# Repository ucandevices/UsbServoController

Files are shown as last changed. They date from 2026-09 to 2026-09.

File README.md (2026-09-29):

# USB-C 12-Channel Servo Controller

Open-source alternative to the [Pololu Mini Maestro 12](https://www.pololu.com/product/1352)
that speaks the **Maestro serial protocols**, so Maestro libraries work unchanged —
plus USB-C, servo-rail current and voltage sensing, on-board scripts. Built for JLCPCB
turnkey assembly, **≈ $4.43 per board at 100 units** against $29.95 for the Maestro.

| | |
|---|---|
| MCU | WCH **CH32V203C8T6**, RISC-V 96 MHz, LQFP-48 |
| Channels | 12 hardware PWM, 50 Hz, 0.5 µs; travel limits per channel (64–4080 µs, 500–2500 default); analog input on 0–7 |
| Host interface | USB-C, CDC serial (no driver); ASCII protocol and the Pololu Maestro Compact / Pololu / Mini SSC protocols |
| Servo power | separate rail on a 5.08 mm screw terminal, 5–13.2 V full function, ~5 A total |
| Sensing | rail current (5 mΩ + INA180A2) and voltage (÷4), overcurrent / LiPo undervoltage cut-off |
| PCB | 66 × 38 mm, 2 layers, all parts top side, 4 × M3 |
| Status | **first board verified on hardware 2026-09-28** — `selftest.py --rail --move` 58/58; channels 1–11 not yet driven with a real servo |

| Document | For |
|---|---|
| [`USER.md`](USER.md) | using the board: wiring, power, tools, command reference, flashing |
| [`tools/README.md`](tools/README.md) | host tools: library, CLI, GUI, scripts, MCP server, release builds |
| this file | design: why each choice, BOM and cost, limitations, what is left before fab |

---

## 1. Quick start

```sh
pip install -r tools/requirements.txt
python tools/servogui.py              # GUI (or --mock with no hardware)
python tools/servoctl.py set 0 1500   # CLI
cd embedded-ch32 && make flash        # build + flash over USB, ~3 s, no jumper
```

**Downloads:** firmware images and the prebuilt GUI for Windows and Linux are on the
[Releases page](https://github.com/ucandevices/UsbServoController/releases/latest).
To build the GUI yourself: `python tools/build_release.py` → `tools/dist/`.

---

## 2. Why the CH32V203C8T6

The hard requirement was a **USB bootloader in ROM**, so a blank chip can be
flashed over USB-C with no programmer. That rules out the STM32F103 the design
started on (USART-only bootloader). Of LQFP-48 parts that have one and are
stocked at JLCPCB:

| Candidate | USB boot on blank chip | Stock | $@100 |
|---|---|---|---|
| **CH32V203C8T6** (chosen) | ✅ | 8,643 | **0.877** |
| CH32X035C8T6 / CH32F203C8T6 | ✅ | ~500 | 0.72 / 1.02 |
| AT32F415CBT7 | ✅ | 10,518 | 1.319 |
| STM32F072C8T6 | ✅ | 2,945 | 2.495 |

Cheapest part with real inventory, a third the price of the STM32F072, and
pin-compatible with the STM32F103 layout (32 of 33 connected pins identical).

Costs of the choice:

- **RISC-V firmware**, WCH HAL, no CubeMX.
- **An ST-Link will not work.** Debug is WCH 2-wire SDI on J9 — needs a
  **WCH-LinkE**. Routine flashing is over USB, so the probe is only for debugging.
- **PB2 is BOOT1** on this chip, so it is tied low by R17 (5.1 kΩ).

---

## 3. Hardware

```
                            U4 INA180A2 (Kelvin across R18) ─► PA5 I_SENSE
J2 Servo V+ ── R18 5mΩ ──┬────────► servo header V+ rail (unfused)
  (VSRV_RAW)              ├─ R19..R22 ÷4 ─► PA4 V_SENSE
                          └─ JP1 ──D2──┐
                                       ├─► HT7533-1 ─► 3V3 ─► CH32V203, LED
USB-C VBUS 5V ─────────────D1──────────┘
GND: one continuous plane, common to both supplies
```

- **Two supply domains, one ground.** D1/D2 are a diode-OR so neither feeds the
  other. Every servo amp crosses R18, so the current reading covers the whole board.
- **JP1** (2-pin header, open by default): fit a shunt cap to run the logic from
  the servo supply with no USB — the Maestro's `VSRV=VIN` block.
- **JP2** (2-pin header): BOOT0 high, for first flash / recovery only.
- **Logic draw ≈ 15 mA**, so the HT7533-1 (100 mA, 2.5 µA quiescent) dissipates
  0.07 W even from 2S LiPo.
- **USB-C**: CC pull-downs R14/R15, SRV05-4 clamps D+, D−, CC1, CC2.
- **Servo signals** are 3.3 V through 220 Ω (R1–R12). Headers are SIG / V+ / GND.

### Channel map

| Ch | 0 | 1 | 2 | 3 | 4 | 5 | 6 | 7 | 8 | 9 | 10 | 11 |
|---|---|---|---|---|---|---|---|---|---|---|---|---|
| Pin | PA0 | PA1 | PA2 | PA3 | PA6 | PA7 | PB0 | PB1 | PA8 | PA9 | PA10 | PB8 |
| Timer | T2C1 | T2C2 | T2C3 | T2C4 | T3C1 | T3C2 | T3C3 | T3C4 | T1C1 | T1C2 | T1C3 | T4C3 |
| Analog | ✅ | ✅ | ✅ | ✅ | ✅ | ✅ | ✅ | ✅ | — | — | — | — |

Reserved: PA4/PA5 rail sensing · PA11/PA12 USB · PA13/PA14 SDI · PD0/PD1 crystal ·
PC13 LED · PB2 BOOT1. LQFP-48 has only 10 ADC pins, and PA4/PA5 went to sensing,
so analog is **8 of 12** — the Maestro 12 has all twelve.

### Rail sensing

| | Current (R18 + U4) | Voltage (R19–R22) |
|---|---|---|
| Parts | 5 mΩ 1 W shunt, INA180A2 gain 50, high side | 4 × 5.1 kΩ, ÷4, 100 nF |
| Full scale | 13.2 A | 13.2 V |
| Resolution | ≈ 3.2 mA | ≈ 3.2 mV |

High side keeps the ground plane unbroken. It measures **total** rail current,
not per channel. The ADC reference is VDDA = the LDO output (no VREF+ on
LQFP-48), so readings are good for thresholds, not calibrated metering. The
firmware trips all channels off after 5 bad readings (~50 ms): 5 A default
overcurrent, and undervoltage chosen automatically (2S → 6.4 V, 3S → 9.6 V,
anything else off). Details in USER.md §4.4.

### Power limits

| Limit | Set by | Value |
|---|---|---|
| Absolute max on J2 | C15/C16, 16 V electrolytics | **16 V** |
| Full function (voltage sense) | ÷4 divider | **13.2 V** |
| Continuous current | 2.4 mm pour between header rows | **~5 A** (6.1 A at 20 °C rise) |

The 24 A terminal is not the limit; the copper behind it is.

### PCB

2 × 1 oz, 1.6 mm, 0.2 mm min trace/space, 0.3/0.6 mm vias. GND is a solid pour
on both layers; SERVO_V+ is carried by three priority-ordered top-layer zones.
Headers along the bottom edge, USB-C right, screw terminal left, MCU centre.

> ⚠️ **F8 (Update PCB from Schematic) deletes H1–H4** — they have no schematic
> symbol. Untick *Delete footprints with no symbols*, or re-add them at
> (16, 4), (61.5, 4), (16, 33), (61.5, 33).

> ⚠️ **HT7533-1 is not pin-compatible with the AMS1117** it replaced (SOT-89:
> GND / VIN+tab / VOUT). The tab is VIN.

---

## 4. Bill of materials and cost

Class: **B** Basic · **P** Preferred (both fee-free) · **E** Extended ($3.07 feeder fee if SMT).

| Ref | Part | LCSC | Class | Qty | $/board |
|---|---|---|---|---|---|
| U1 | CH32V203C8T6, LQFP-48 | C3001172 | E | 1 | 0.8770 |
| U2 | HT7533-1, SOT-89-3 | C14289 | B | 1 | 0.1430 |
| U3 | SRV05-4 ESD, SOT-23-6 | C558418 | E | 1 | 0.0270 |
| U4 | INA180A2, SOT-23-5 | C192764 | E | 1 | 0.1920 |
| J1 | USB-C 16P TYPE-C-31-M-12 | C165948 | E | 1 | 0.1860 |
| J2 | Screw terminal 5.08 mm 2P | C474952 | E (THT) | 1 | 0.1920 |
| J3–J8 | Pin header 1×6 2.54 mm | C37208 | E (THT) | 6 | 0.2520 |
| JP1, JP2 | Pin header 1×2 2.54 mm | C358684 | E (THT) | 2 | 0.0180 |
| Y1 | Crystal 8 MHz SMD5032 | C115962 | B | 1 | 0.2450 |
| D1–D2 | B5819W, SOD-123 | C7420330 | P | 2 | 0.0340 |
| D3 | LED red 0603 | C2286 | B | 1 | 0.0070 |
| R1–R13 | 220 Ω 0603 (servo series + LED) | C22962 | B | 13 | 0.0650 |
| R14–R17, R19–R22 | 5.1 kΩ 0603 | C23186 | B | 8 | 0.0160 |
| R18 | 5 mΩ 1 W shunt, 1206 | C7419996 | E | 1 | 0.0370 |
| C1–C8, C17–C18 | 100 nF 0603 X7R | C14663 | B | 10 | 0.1200 |
| C9–C11 | 10 µF 0603 X5R | C19702 | B | 3 | 0.0960 |
| C12 | 1 µF 0603 | C15849 | B | 1 | 0.0170 |
| C13–C14 | 30 pF 0603 C0G | C1658 | B | 2 | 0.0160 |
| C15–C16 | 470 µF 16 V electrolytic | C46550400 | E | 2 | 0.2140 |
| | | | | **58** | **$2.7540** |

J9 (SDI) is not fitted. Shunt caps (`C100114`, two per board) cannot be fitted
by JLCPCB — order them loose, ≈ $1.80 per 100.

| 100 units | Total | Per board |
|---|---|---|
| Components | $275.40 | $2.754 |
| Assembly: setup $8.18, stencil $1.53, SMT 167 joints $26.72, THT 42 joints $68.88 + $3.58, 6 feeder fees $18.42 | $127.31 | $1.273 |
| PCB fabrication (est.) | ~$40 | ~$0.40 |
| **Total** | **≈ $443** | **≈ $4.43** |

Excludes shipping and duties. Prices are LCSC qty-100; stock checked
2026-09-19/20 (CH32V203 the thinnest at 8,643) — **re-verify before ordering**.

What drives cost:

- **Through-hole soldering is 57 % of assembly.** J3–J8 cost $0.25 in parts and
  $0.59 in hand soldering. SMT-only with loose headers would cut assembly to
  $0.55/board.
- **Unique Extended SMT parts, not unit price.** Hence 220 Ω doubles as the LED
  resistor, 5.1 kΩ serves CC1/CC2/BOOT0/BOOT1/divider, one SRV05-4 replaces
  discrete TVS diodes, and JP1/JP2 share one header part.

---

## 5. Firmware (`embedded-ch32/`)

RISC-V, WCH `ch32v20x` HAL and USB device library, xPack `riscv-none-elf-gcc`
15.2 (`make GCC_PATH=...` to override). Version `USBServoController 0.4`.

| Flash region | Address | Size | Contents |
|---|---|---|---|
| Bootloader | 0x0000 | 12 KB | own USB CDC bootloader (`bootloader/`) |
| Application | 0x3000 | 48 KB | servo firmware |
| Script | 0xF000 | 2 KB | stored board script |
| Settings | 0xF800 | 256 B used | travel limits, Maestro speed/accel (`User/settings.c`, `W`) |

Layout lives in `User/flash_layout.h` and both `Link.ld` files.

```sh
make                 # build/USBServoController-ch32.{elf,hex,bin}
make flash           # BOOT command -> bootloader -> write, CRC-32 check, restart (~3 s)
make hosttest        # on the PC: sense.c protection (21 supply scenarios), maestro.c protocol, ramps and limits (11)
python tools/verify_pinmap_ch32.py   # schematic <-> pin table <-> firmware
```

**Blank chip or recovery:** `make full`, fit JP2, plug in USB,
`wchisp flash build/USBServoController-ch32-full.bin`, remove JP2, **replug**.
Jumping to the ROM bootloader from firmware does not work on this chip (tested),
which is why the board has its own.

**Timing:** 96 MHz timers, PSC 47 → 0.5 µs ticks, ARR 39999 → 20 ms frame.
0.25 µs would need a 4 MHz tick, which only fits 16 bits at ≥ 100 Hz.

**Protocol:** one ASCII command per line, one `OK` / `OK <value>` / `ERR <reason>`
reply. Servo (`S G E X A`), rail sensing (`I U F L P C Z N`), stored script
(`QC QA QS QI QG QR QX`), system (`V BOOT`). Full reference: USER.md §4.3.

**Maestro protocols** (`User/maestro.c`): bytes of `0x80` and above are Pololu
Maestro commands — Compact, Pololu (device 12) and Mini SSC framings, with
on-board speed and acceleration ramps in the Maestro's units. Both protocols
share the port. Reference: USER.md §4.3b.

**Script engine** (`User/script.c`): up to 254 instructions — move with ramp
time, wait, sync, loop, jump, analog wait/branch — compiled from text by
`tools/servoscript.py`, runs without a PC, optionally at power-up.

### Toolchain traps

- **`interrupt("WCH-Interrupt-fast")` is silently dropped by upstream GCC** —
  one warning, then ISRs end in `ret` instead of `mret`. Use
  `interrupt("machine")`.
- **GCC 15 defaults to C23**, where `bool` is a keyword; WCH's `usb_type.h`
  typedefs it. Built with `-std=gnu11` and a patched header.
- **`-march=rv32imac_zicsr_zifencei`** — GCC 15 split CSR and fence.i out.
- **No `printf` at runtime.** A WCH example `printf` in the USB suspend hook hung
  the ISR at bring-up, and PA9 (USART1 TX) is a servo output.

Modified vendor files: `usb_endp.c` (OUT endpoint → parser), `usb_prop.c`
(line coding via `User/cdc_glue.c`), `ch32v20x_it.c` (TIM2 drives servos).

---

## 6. Limitations and Maestro 12 comparison

| Maestro 12 | This board | Fix |
|---|---|---|
| mini-USB | **USB-C** | better |
| no rail sensing | **current + voltage, overcurrent and LiPo cut-off** | better |
| $29.95 | **≈ $4.43** | better |
| 5–16 V servo supply | 5–16 V (13.2 V full function) | parity |
| 12 analog inputs | 8 | respin (pin limit) |
| 5 V signals, 5 V user pin | 3.3 V, no 5 V rail | respin |
| TTL serial, daisy-chain, `ERR` pin, 3 LEDs | USB only, 1 LED | respin |
| Pololu / Compact / Mini SSC protocols | **supported** (0.4): set target(s), speed, acceleration, get position / moving state / errors, go home | parity |
| per-channel min/max 64–4080 µs, 1–333 Hz | **per-channel limits 64–4080 µs**, saved with `W`; fixed 50 Hz | rate: firmware |
| 0.25 µs resolution | 0.5 µs | firmware, at ≥ 100 Hz |
| Speed + acceleration in firmware | **supported** through the Maestro protocol | parity |
| Settings, home positions, startup behaviour in flash | limits and speed/accel stored; no home positions, all channels boot off | firmware |
| Error register, serial-timeout failsafe | protocol-error bit only; no serial timeout | firmware |
| 8 KB script language | 254-instruction motion script | simpler |
| Maestro Control Center | own GUI (`servogui.py`) | Pololu VID-locked |
| 28 × 36 mm | 66 × 38 mm | — |

Other known gaps: **no reverse-polarity protection on J2** — a reversed pack
kills U4 and can vent C15/C16 (a P-FET ideal diode, ≈ $0.19, was deliberately
left out); the current-sense zero (`Z`) is lost at power-off.

### Joining the Maestro ecosystem

Maestro software splits in two. **Runtime control** — nearly every community
library (FRC4564/Maestro, maestro-servo, ROS 1/2 drivers, Node, C++) — opens
the CDC port and speaks the Pololu/Compact/Mini SSC byte protocols **without
checking USB IDs**. **Configuration** (Control Center, `UscCmd`) uses control
transfers bound to Pololu's VID `0x1FFB` and can never work here.

Firmware 0.4 implements those serial protocols, so the runtime libraries work
unchanged: verified on hardware with an unmodified FRC4564 `maestro.py`
(targets, speed, acceleration, position, moving state). One dispatch on the
first byte serves everything: `0xAA` Pololu, `0xFF` Mini SSC, `0x80–0xFE`
Compact, printable ASCII the existing protocol.

Still different from a Maestro: 0.5 µs output steps (0.25 µs needs ≥ 100 Hz
frames), a fixed 50 Hz rate, no home positions, CRC or serial timeout.
Per-channel travel limits (64–4080 µs) and start-up speed/acceleration are
stored on the board with `W` — the GUI's gear button sets the limits. Next steps: configurable frame rate →
serial-timeout failsafe → home positions.

---

## 7. Design notes

**JP1 is a header, not a power-mux IC.** Automatic muxing above 6 V needs an
ideal-diode controller plus FETs (LM5050 +$2.12/board); TPS2116 stops at 5.5 V.
The diode-OR costs $0.03 and JP1 carries only the ~15 mA logic current. A header
and shunt cap ($0.05) beat slide switches on price and have no voltage limit of
their own.

**JP2 is a header too**, so the one jumper every board needs for its first flash
needs no soldering iron.

**HT7533-1 replaced the AMS1117**, which was 66× oversized, drew 5 mA quiescent
and wanted 22 µF tantalum. The HT7533 is cheaper, takes 30 V, and is stable with
the existing 10 µF ceramics.

---

## 8. Repository layout

| Path | Contents |
|---|---|
| `PCB/usbservocontroller/` | KiCad 10 schematic and board; `production/` = Fabrication Toolkit output |
| `embedded-ch32/` | application firmware (`User/`), bootloader (`bootloader/`), host test (`test/`) |
| `embedded-ch32/tools/` | `verify_pinmap_ch32.py`; put a `wchisp` download here (not in the repo) |
| `tools/` | host tools — see [`tools/README.md`](tools/README.md) |
| `USER.md` | user manual |

> The Fabrication Toolkit reads `LCSC` from **footprints**, not symbols. After a
> schematic sync, check `grep -c 'property "LCSC"' usbservocontroller.kicad_pcb`
> (58 today) — a missing field shows as "part not found" at JLCPCB.

---

## 9. Before the next fab run

Checked against the files on 2026-09-29: ERC **0**, DRC **11 errors**, all the
inherent header courtyard overlaps (three rows on a 2.54 mm grid), 0 unconnected.

1. **Fix JP2's board reference.** The footprint is labelled `BOOT0_SEL` instead
   of `JP2`, so DRC reports JP2 missing plus an extra footprint, and fab files
   would carry the wrong designator. Run F8 (with *Delete footprints with no
   symbols* unticked).
2. **Set DNP on J9 and exclude H1–H4 from BOM/position files.** Neither flag is
   set yet, so `EXCLUDE DNP` in `fabrication-toolkit-options.json` does nothing.
3. **R13 220 Ω → 1 kΩ** (C21190, Basic). PC13 is rated 3 mA; 220 Ω drives the
   LED at ~6 mA. Works on the first board, but out of spec.
4. **Remove the 3 duplicated vias** (GND at 11.5, 35.2; I_SENSE and V_SENSE near
   32, 16–18) and decide on the courtyard errors — shrink the courtyards or add
   DRC exclusions so a real error cannot hide among them.
5. **Regenerate `production/`** — it dates from 2026-09-20, before the last
   board edit. Then check that H1–H4 and J9 are gone from `bom.csv` and
   `positions.csv`.
6. **Re-verify JLCPCB stock** (§4).

Re-run the checks with `kicad-cli sch erc usbservocontroller.kicad_sch` and
`kicad-cli pcb drc --schematic-parity usbservocontroller.kicad_pcb`.

---

## License

[MIT](LICENSE) — hardware design files, firmware and host tools.

Files carrying a WCH (Nanjing Qinheng Microelectronics) copyright header — the
`ch32v20x` HAL, USB library, startup code and the WCH-derived files in
`embedded-ch32/User/` — remain under WCH's own terms, which limit their use to
WCH microcontrollers.

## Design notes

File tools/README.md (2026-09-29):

# `tools/` — host-side tooling

Everything here runs on the PC and talks to the board over its USB CDC port. It
is separate from `embedded-ch32/tools/`, which holds `verify_pinmap_ch32.py` —
that one checks the schematic against the firmware and never opens a serial port.

| File | What it is |
|---|---|
| `usc.py` | the driver library — one class, one method per protocol command |
| `servoctl.py` | the CLI, built on `usc.py` |
| `servogui.py` | desktop GUI: sliders, limits, speed, analog inputs, poses & sequences, rail graph, CSV log, flashing |
| `flash.py` | reflash over USB through the board's bootloader, no jumper |
| `servoscript.py` | compile / upload / run scripts the board executes without a PC |
| `servo_mcp.py` | MCP server: AI-agent control with guardrails (needs `mcp>=2`) |
| `build_release.py` | standalone GUI for Windows / Linux (PyInstaller), see section 5 |
| `servoconfig.py` | channel names, limits, poses, sequence — shared by GUI and MCP |
| `examples/` | example board scripts |
| `selftest.py` | first-power-on acceptance test, exit code 0/1 |
| `requirements.txt` | `pyserial`, and nothing else |

```sh
pip install -r requirements.txt

python servoctl.py ports            # find the board
python servoctl.py info             # version, all 12 channels, rail status
python servoctl.py set 0 1500       # move channel 0 to neutral
python servoctl.py sweep 0          # walk it, to check the wiring
python servoctl.py monitor          # watch current and voltage
python servoctl.py stop             # panic stop
python selftest.py --move --rail    # full acceptance run on a new board
```

Every one of those takes `--mock`, which swaps in an in-process emulator of the
firmware's parser and needs no hardware. **The board has never been powered
(README §9), so `--mock` is the only way this tooling has been exercised so
far** — it proves the host code, not the board.

---

## 1. Investigation: what tooling is actually used to drive servos

The question worth answering before writing anything was *what shape* this
tooling should take. The answer comes from the Maestro ecosystem, which README
§6.2 already maps — this section adds what that implies for the host side.

### The ecosystem is Python + pyserial, almost without exception

Every community client for the Mini Maestro is a thin wrapper around pyserial.
[FRC4564/Maestro](https://github.com/FRC4564/Maestro), the most-copied one,
is a single class requiring the pyserial module; it opens a port by name and
writes protocol bytes. [kalhamaar/Maestro](https://github.com/kalhamaar/Maestro)
and [mpiannucci/MiniMaestro](https://github.com/mpiannucci/MiniMaestro) are the
same shape, and [DaveForan/PololuMaestro](https://github.com/DaveForan/PololuMaestro)
is a Python-3/PEP-8 refresh of the same code. Pololu's own documentation ships a
`maestro.py` class that controls a Maestro over its serial interface.

There is no meaningful C++, Rust or Go layer in daily use, and no USB-HID or
libusb layer for *runtime control* at all — the native-USB path exists only for
configuration and script upload, and is what binds to Pololu's vendor ID.

**So: Python, pyserial, one class, no framework.** That is what `usc.py` is.

### The reference GUI, and what it does

Pololu's Maestro Control Center is the thing people actually use day to day, and
it is worth copying the *shape* of. Its tabs, from Pololu's user's guide:

| Tab | What it gives you |
|---|---|
| **Status** | one row per channel: an enable checkbox, a target slider, a position indicator — real-time control and monitoring |
| **Channel Settings** | per-channel mode (servo / input / output), min, max, neutral, speed, acceleration |
| **Sequencer** | a list of *frames*, each a full set of channel positions plus a duration in ms, played back or exported to a script |
| **Script** | write, single-step and run scripts stored on the controller |

The Status tab is the one that matters first, and it is the one a CLI can only
approximate — `servoctl.py monitor` is the closest thing here. It is free, and
runs on Windows and Linux.

**It can never work against this board.** Control Center, `UscCmd` and the
Pololu USB SDK all bind to USB vendor ID `0x1FFB`, which is Pololu's USB-IF
assignment. That is not clonable, so an equivalent host tool is part of this
project rather than optional polish — which is the reason `tools/` exists as a
first-class directory and not a scratch folder.

### Port discovery is a solved convention

pyserial's `serial.tools.list_ports.comports()` returns objects carrying `vid`,
`pid`, `serial_number` and a description, and matching on VID/PID is the
standard way host tools find their board. The wrinkle here is that the firmware
ships **WCH's stock CDC identifiers, `0x1A86:0xFE0C`** (`USBLIB/CONFIG/usb_desc.c`),
not its own — so VID/PID alone would also match any other WCH CDC device on the
machine. `usc.py` therefore filters on VID/PID *and then* probes each candidate
with `V`, keeping the one that answers with the version string. Projects that hit
the same problem solve it the same way: CircuitPython's tooling matches on the
CDC interface *name* rather than on IDs for exactly this reason.

> Worth considering for a later firmware revision: WCH does not police its VID,
> but shipping a distinct PID and a product string of your own would make
> discovery exact instead of probabilistic.

### What this means for the ordering of work

1. **A Python library + CLI first.** It matches what the ecosystem already does,
   it is what a person needs on the bench the hour the first board arrives, and
   everything else is built on top of it. ← *this directory*
2. **A Pololu/Compact protocol layer in the firmware second** (README §6.2),
   because it makes all fourteen libraries in that table work unmodified. At
   that point `usc.py` becomes a *second* way in, not the only way.
3. **A Control Center equivalent last**, once the firmware has settings worth
   persisting. A sequencer — frames of positions plus durations — is the single
   most-copied feature and is pure host-side code; it needs nothing from the
   firmware that `S` does not already provide.

---

## 2. `usc.py` — the library

```python
from usc import ServoController

with ServoController.open() as dev:        # or .open("COM5"), or .mock()
    print(dev.version())
    dev.set_us(0, 1500)                    # S 0 1500 -- also enables ch0
    print(dev.get_us(0))                   # G 0
    print(dev.status())                    # F -> Status(faults, mA, mV, rail)
    dev.stop_all()                         # X
```

One method per command in README §5: `version`, `set_us`, `get_us`, `enable`,
`disable`, `stop_all`, `read_analog`, `current_ma`, `voltage_mv`, `read_raw`,
`tare`, `status`, `clear_faults`, `set_limits`, `reboot_to_bootloader`. Anything
not covered goes through `dev.command("...")`, which returns the raw reply line
and raises `DeviceError` on `ERR`.

Two firmware behaviours the library documents rather than hides, because both
surprise people:

- **`S` enables the channel.** `Servo_SetPulseUs()` sets `s_enabled`
  unconditionally, so setting a pulse width is what starts a servo moving. There
  is no "set the target but stay off".
- **`G` returns `0` for a disabled channel**, not its last pulse width. So
  `set_us(0, 1500); disable(0); get_us(0)` gives `0`, and the stored width is
  not readable back. `positions()` returns the same 0-means-off convention.

### The emulator

`MockDevice` reimplements `protocol.c`'s dispatch and a simplified `sense.c` in
about 150 lines. It exists because the board has never been run, and it is
deliberately *not* a simulator: no timers, no ADC noise, no USB. It catches
host-side mistakes — a malformed command, a misparsed reply, a wrong error
string — and nothing else. Simulated current is `12 mA + 120 mA per enabled
channel`, enough for the fault logic to be exercised.

---

## 3. `selftest.py` — the bring-up test

Ordered so that a wiring fault cannot become a damaged servo: everything
read-only happens before anything moves, and `--move` is opt-in.

```
1. Identity          V answers, and says 12ch
2. Boot state        all 12 channels report disabled  <- an unconfigured board must not move
3. Error handling    seven rejections, each with the right ERR reason
4. Rail sensing      F/I/U/N; I_SENSE and V_SENSE not pinned at 0 or 4095
5. Analog inputs     0-7 return counts, 8-11 return ERR noanalog
6. Movement          --move only, one channel at a time, each parked before the next
7. Current sense     moves ch0, checks the peak current rises (servo on ch0)
8. Panic stop        X really does disable everything
```

It always ends with `X`, including on failure or Ctrl-C, so a failed run leaves
nothing energised. Exit code 0/1 makes it usable as a production go/no-go test.

Checks 4 and 7 are the ones that matter most on a first article, because they
are what distinguishes "R18/U4/PA5 are correctly assembled" from "the firmware
compiles". A current reading that does not change when a channel is enabled means
the sense path is not connected, whatever the numbers look like.

---

## 4. Two findings from reading the firmware alongside this

**A latched fault does not block `S`.** README §5 states that while a fault is
latched, `E <ch> 1` is refused with `ERR fault` — and it is, in `protocol.c`'s
`case 'E'`. But `case 'S'` has no such check, and `Servo_SetPulseUs()` sets
`s_enabled = true`. So `S 0 1500` re-energises a channel straight through the
interlock, and `sense.c` will only trip again after `SENSE_TRIP_COUNT` further
task periods. The fix is one line — the same `Sense_Faults() != 0` guard in
`case 'S'` — but it is a firmware change, so it is noted here rather than made.
Until then, host code must treat the interlock as advisory: `selftest.py` checks
`status()` after each movement instead of relying on it.

**`BOOT` reboots into the board's own USB bootloader** (verified on hardware
2026-09-28). It is what `flash.py` uses to reflash without a jumper: `python
flash.py [app.bin] [--port COMx]` — BOOT, erase, write (page 0 last), CRC-32
verify, start; about 3 s. `servoctl.py boot --yes` does only the first step and
leaves the board waiting in the bootloader (LED at 5 Hz). The bootloader
protocol is documented in `embedded-ch32/bootloader/bl_main.c`.

---

## 5. Standalone GUI release (`build_release.py`)

`servogui.py` packaged with PyInstaller into one executable, zipped with
`examples/` and the application firmware image (so the Firmware tab works):

    python build_release.py                       # Windows -> dist/ServoGUI-windows-x64.zip
    wsl -d Ubuntu -- ~/servogui-venv/bin/python build_release.py   # Linux -> dist/ServoGUI-linux-x64.tar.gz

It builds for the OS it runs on, so the Linux build runs in WSL (venv at
`~/servogui-venv` with `pyinstaller pyserial`; needs `python3-tk`). A frozen
build keeps `servogui.json` next to the executable and flashes by re-running
itself as `ServoGUI --run-flash <image>`. On Linux the user must be in the
`dialout` group to open the serial port.

## Sources

- [FRC4564/Maestro](https://github.com/FRC4564/Maestro) — the most-copied Python client
- [kalhamaar/Maestro](https://github.com/kalhamaar/Maestro), [mpiannucci/MiniMaestro](https://github.com/mpiannucci/MiniMaestro), [DaveForan/PololuMaestro](https://github.com/DaveForan/PololuMaestro)
- [Pololu Maestro Servo Controller User's Guide](https://www.pololu.com/docs/0j40/all) — and its [Status](https://www.pololu.com/docs/0J40/4.a), [Channel Settings](https://www.pololu.com/docs/0J40/4.b) and [Sequencer](https://www.pololu.com/docs/0J40/4.c) tabs
- [Pololu related resources](https://www.pololu.com/docs/0J40/10) — the official `maestro.py`
- [pySerial `serial.tools.list_ports`](https://pyserial.readthedocs.io/en/stable/tools.html)

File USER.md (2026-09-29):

# USB-C 12-Channel Servo Controller — User Manual

This is the manual for **using** the board: what is on it, how to wire it, how to
drive it from a PC, and how to build and flash the firmware. The design
rationale, costs and known limitations live in [`README.md`](README.md); this
file only repeats what you need at the bench.

> ⚠️ **Prototype status.** Board revision v1 has **not yet been run on real
> hardware.** Everything here is taken from the schematic, the board file and the
> firmware source, and the host tools have only been exercised against their
> built-in emulator (`--mock`). Treat the first boards as bring-up units and run
> the self-test (§3.4) before trusting one with servos you care about.

**Contents**

1. [Hardware manual](#1-hardware-manual) — board tour, connectors, power, wiring
2. [First power-on](#2-first-power-on) — the safe sequence for a new board
3. [Tooling manual](#3-tooling-manual) — `servoctl`, `selftest`, the Python library
4. [Embedded manual](#4-embedded-manual) — protocol, behaviour, build, flash
5. [Troubleshooting](#5-troubleshooting)
6. [Quick reference card](#6-quick-reference-card)

---

## 1. Hardware manual

### 1.1 What it is

A 12-channel hobby-servo controller driven over USB-C. The PC sends text
commands to a virtual serial port; the board turns them into standard RC servo
pulses. It also measures the **current and voltage of the servo supply** and
can shut every servo off on overcurrent or a flat battery.

| | |
|---|---|
| MCU | WCH CH32V203C8T6 (32-bit RISC-V, 96 MHz) |
| Host interface | USB-C, appears as a serial (CDC) port — no driver on Windows 10+, Linux, macOS |
| Servo outputs | 12 channels, 3.3 V logic pulses, 50 Hz, 0.5 µs resolution; 500–2500 µs by default, settable per channel from 64 to 4080 µs |
| Analog inputs | channels 0–7 only, **0–3.3 V** |
| Servo supply | separate, via screw terminal J2 — see §1.4 for limits |
| Rail monitoring | servo-rail current (0–13.2 A range) and voltage (0–13.2 V range) |
| Indicator | one red LED (heartbeat) |
| Size | 66 × 38 mm, 4 × M3 mounting holes |

### 1.2 Board tour

Hold the board **component side up, USB-C connector on the right.**

```
                                  TOP EDGE
 ┌─────────────────────────────────────────────────────────────────────┐
 │ (H1)          J9  SDI debug (not fitted)      JP2                (H2) │
 │               3V3 DIO CLK RST GND             BOOT0      USB SERVO   │
 │                ○   ○   ○   ○   ○               ▯          CONTROLLER │
 │  C15                                           ▯          v1         │
 │ (470µF)                 Y1        ┌──────┐                        ┌──┤
 │                                   │  U1  │                   J1   │  │ USB-C
 │  J2 SERVO PWR  ─                  │CH32V │                        │  │
 │   [−]  GND                        └──────┘                        └──┤
 │   [+]  V+   +                                                        │
 │                        0  1  2  3  4  5  6  7  8  9  10 11           │
 │  JP1 ▯▯   VSRV    SIG  ○  ○  ○  ○  ○  ○  ○  ○  ○  ○  ○  ○   SIG      │
 │           LOGIC   V+   ○  ○  ○  ○  ○  ○  ○  ○  ○  ○  ○  ○   V+   D3  │
 │ (H3)              GND  ○  ○  ○  ○  ○  ○  ○  ○  ○  ○  ○  ○   GND  LED │
 └─────────────────────────────────────────────────────────────────(H4)┘
                                 BOTTOM EDGE
```

| Ref | What | Where |
|---|---|---|
| **J1** | USB-C — data and logic power | right edge |
| **J2** | Servo power in, 5.08 mm screw terminal | left edge. **Lower screw = `+`**, upper screw = `−` (GND). Silkscreen `+` / `−` marks each side. |
| **J3–J8** | 12 servo ports, 3 rows × 12 | along the bottom. Channel numbers printed above; row names `SIG` / `V+` / `GND` printed at the right end |
| **JP1** | "VSRV / LOGIC" jumper — power the logic from the servo supply | left edge, below J2 |
| **JP2** | BOOT0 jumper — enter the USB bootloader | top edge, centre |
| **J9** | WCH SDI debug header, **not fitted** | top edge, left of centre |
| **D3** | red status LED | bottom right |
| **H1–H4** | M3 mounting holes, 3.2 mm | corners; centres 45.5 × 29 mm apart |

### 1.3 Servo ports (J3–J8)

Each **column** is one channel. Each column has three pins, from top to bottom:

| Row | Pin | Standard servo wire colour |
|---|---|---|
| top (toward the chip) | **SIG** — the pulse | orange / yellow / white |
| middle | **V+** — servo power, straight from J2 | red |
| bottom (toward the board edge) | **GND** | brown / black |

This is the standard Futaba/JR/Hitec order, so a normal 3-wire servo plug goes on
**with the dark wire toward the bottom edge.** Channel 0 is on the left,
channel 11 on the right.

| Ch | MCU pin | Timer | Analog in? |
|---|---|---|---|
| 0 | PA0 | TIM2_CH1 | ✅ |
| 1 | PA1 | TIM2_CH2 | ✅ |
| 2 | PA2 | TIM2_CH3 | ✅ |
| 3 | PA3 | TIM2_CH4 | ✅ |
| 4 | PA6 | TIM3_CH1 | ✅ |
| 5 | PA7 | TIM3_CH2 | ✅ |
| 6 | PB0 | TIM3_CH3 | ✅ |
| 7 | PB1 | TIM3_CH4 | ✅ |
| 8 | PA8 | TIM1_CH1 | — |
| 9 | PA9 | TIM1_CH2 | — |
| 10 | PA10 | TIM1_CH3 | — |
| 11 | PB8 | TIM4_CH3 | — |

Every SIG pin has a **220 Ω series resistor** between the MCU and the header.

**What can be connected to a servo port:**

| Device | Works? | Notes |
|---|---|---|
| Standard analog / digital hobby servo | ✅ | the intended use |
| Continuous-rotation servo | ✅ | 1500 µs ≈ stop; trim per servo |
| ESC (brushed or brushless) | ✅ | 1000–2000 µs is inside the range. **See the BEC warning below.** |
| Servos that need 5 V logic pulses | ⚠️ | most accept 3.3 V; a few older ones do not |
| Potentiometer / 0–3.3 V sensor on ch 0–7 | ⚠️ | read with the `A` command — see limits in §1.7 |
| 5 V sensor output | ❌ | inputs are 0–3.3 V only; 5 V will inject current into the MCU |
| LEDs, relays, logic outputs | ❌ | firmware has no digital-output mode yet |
| UART / TTL serial device | ❌ | firmware does not support it yet |

> ⚠️ **ESC BEC warning.** Many ESCs *output* 5–6 V on their red wire (a "BEC").
> Plugged into this board, that output lands on the shared **V+ rail** together
> with whatever is on J2. Two supplies fighting on one rail can damage both.
> If you plug in an ESC with a BEC while J2 also has a supply, **pull the red
> wire out of the ESC's plug** (or use only the ESC's BEC to power the rail and
> leave J2 empty).

### 1.4 Power

The board has **two independent power domains** that share a common ground:

- **Logic** (MCU, USB, LED) — 3.3 V from an on-board regulator, fed from USB-C
  or, if JP1 is fitted, from the servo supply.
- **Servo rail** (V+ row on all 12 ports) — whatever you connect to J2, passed
  straight through. **The board does not regulate servo power.**

```
  USB-C VBUS 5V ──D1──┐
                      ├──► HT7533 3.3V LDO ──► MCU, LED
  J2 + ──[5mΩ shunt]──┼──► V+ on all 12 servo ports
                      │
                      └── JP1 ──D2──┘   (JP1 fitted = logic can run from J2)
  J2 − ─────────────────── GND (common to everything)
```

**Servo supply limits**

| | Value |
|---|---|
| Supply voltage | **choose it to match your servos** — see below |
| Absolute maximum on J2 | **16 V** (set by the 16 V bulk capacitors) |
| Maximum for correct voltage reading | 13.2 V |
| Continuous current, whole board | **≈ 5 A total** across all channels |
| Terminal wire size | 12–22 AWG; use **18 AWG or thicker** for loads over 2 A |

> The screw terminal itself is rated 24 A, but the copper behind it is not.
> Budget about **5 A total** — a dozen small servos holding position, or three
> or four working hard.

**Choosing the servo supply.** Since the voltage on J2 goes straight to every
servo, pick it for your servos, not for the board:

| Supply | Suits |
|---|---|
| 4.8 V (4× NiMH) | standard servos |
| 5–6 V BEC / bench supply | standard servos — the most common choice |
| 7.4 V (2S LiPo), 8.4 V charged | **HV (high-voltage) servos only** |
| 11.1 V (3S LiPo) | almost no servos — only if yours are rated for it |

> ⛔ **No reverse-polarity protection.** Connecting the servo supply backwards
> will destroy the current-sense chip (U4) and can make the two large capacitors
> vent. Check `+` and `−` **before** tightening the screws, every time. Wire the
> supply with the power switched off.

> **Battery protection is automatic for LiPo packs.** About 100 ms after a servo
> supply appears, the firmware recognises a **2S or 3S LiPo** by its voltage and
> sets a 3.2 V/cell cutoff. Any other supply (5 V / 6 V BEC, NiMH, bench supply)
> gets **no** undervoltage cutoff unless you set one. Details and overrides are in
> §4.4.

### 1.5 The two jumpers

Both are 2-pin headers closed with a standard 2.54 mm shunt cap. The board ships
**with both open**; the caps come loose in the bag.

**JP1 — "VSRV / LOGIC": run the logic from the servo supply**

| JP1 | Logic powered from | Use when |
|---|---|---|
| **open** (default) | USB only | normal use with a PC. Recommended. |
| **fitted** | USB **or** servo supply, whichever is higher | the USB port's power is weak (long cable, unpowered hub), or you want the board to stay alive with USB unplugged |

Diodes on both paths stop either supply back-feeding the other, so it is safe
to have USB and J2 connected with JP1 fitted.

> **Standalone operation:** with JP1 fitted and the servo supply on, the board
> runs a stored script with no PC at all — upload it with autorun (§3.1c) and it
> starts at every power-up. Without a stored autorun script, every channel stays
> off after power-up until a host sends commands.

**JP2 — BOOT0: firmware update mode**

| JP2 | At power-up the board runs |
|---|---|
| **open** (normal) | the servo-controller firmware |
| **fitted** | WCH's ROM bootloader — first flash of a blank chip, or recovery (§4.7) |

Routine firmware updates **do not use JP2**: `flash.py` reboots the board into
its own USB bootloader over the serial port (§4.7). JP2 is for a blank chip, or
for recovering a board whose application no longer answers on USB. It is only
read **at power-up** — fit it, *then* plug in USB, and remove it afterwards.

### 1.6 USB-C

- Any USB-C cable to a USB-A or USB-C port works. The board is a USB 2.0
  full-speed device and draws about 15 mA (estimated, not yet measured).
- Either plug orientation works.
- Data lines and the CC pins are ESD-protected.
- USB **never** powers the servos. With only USB connected, the board runs and
  answers commands, but nothing on the V+ row has power.

### 1.7 Electrical limits of the signal pins

| | |
|---|---|
| Output high / low | 3.3 V / 0 V through 220 Ω |
| Analog input range (ch 0–7) | **0 to 3.3 V** — never exceed |
| Analog reading | 12-bit, 0–4095 counts over 0–3.3 V |
| 5 V tolerance | **not guaranteed** — do not feed 5 V into a SIG pin |

> ⚠️ **Analog inputs are shared with outputs.** A channel that is not driving a
> servo is held **low** by the MCU, and is switched to input only for the ~20 µs
> of each reading. So a potentiometer (1–10 kΩ) wired as a divider between 3.3 V
> and GND reads correctly, but a sensor with a strong output will be fighting the
> pin between readings. Keep analog sources high-impedance, and **never** read a
> channel that has a servo plugged in and enabled — the reading briefly
> interrupts its pulse.

> ⛔ **Where to get 3.3 V for a potentiometer.** The servo header has **no
> 3.3 V pin** — its middle row is the servo supply (5–13 V). A pot wired between
> the header's V+ and GND puts up to the full servo voltage on the ADC pin.
> Take 3.3 V and GND from **J9 pin 1 (3V3) and pin 5 (GND)** instead — solder a
> 1×5 2.54 mm header there (§1.8). Wire: pot ends → J9.1 and J9.5, wiper → the
> channel's **SIG** pin (top row).

> ⚠️ **A servo plug reversed by one row** puts V+ on the SIG pin. The 220 Ω
> resistor limits the damage, but at 6–8 V it still pushes 10–20 mA into the MCU
> pin. Check plug orientation before powering J2.

### 1.8 J9 — debug header (developers only)

Not fitted. Solder a 1×5 2.54 mm header if you need live debugging.

| Pin | Signal |
|---|---|
| 1 | 3V3 |
| 2 | SDI_DIO (PA13) |
| 3 | SDI_CLK (PA14) |
| 4 | NRST |
| 5 | GND |

> ⛔ This is **WCH's 2-wire SDI protocol, not ARM SWD.** An ST-Link, J-Link or
> other ARM probe **will not work.** Use a **WCH-LinkE**. You do not need J9 at
> all to update the firmware — that goes over USB (§4.7).

### 1.9 Status LED (D3)

| LED | Meaning |
|---|---|
| one short blip per second | running, idle, servo supply present on J2 |
| **two** short blips per second | running, idle, **no servo supply** on J2 |
| **steady on** | a **stored script is running** (§3.1c) |
| fast even flashing, 10 Hz | **fault latched** (overcurrent or undervoltage): every channel was dropped. Clear it with `C`, `servoctl.py clear` or the GUI's **Clear faults** |
| even flashing, 5 Hz | in the USB **bootloader** (after `BOOT`, or an interrupted flash) — run `tools/flash.py` |
| off | no power, or the ROM bootloader (JP2 fitted) |
| stuck on with no script running, or stuck off while powered | firmware has hung — unplug and re-plug |

Only one pattern shows at a time; a fault outranks a running script, which
outranks the idle patterns.

---

## 2. First power-on

Follow this order on a new board. It is arranged so that a wiring or assembly
fault shows up **before** anything moves.

1. **Inspect.** Look for solder bridges on U1 (the square 48-pin chip) and on the
   USB-C connector. Check that JP1 and JP2 are **open**.
2. **USB only.** Plug in USB-C, no servo supply, no servos. The LED should start
   blinking within a second.
3. **Find the port.**
   ```sh
   cd tools
   pip install -r requirements.txt
   python servoctl.py ports
   ```
4. **Safe self-test** — nothing moves:
   ```sh
   python selftest.py
   ```
   It must end with `RESULT: PASS`. The rail-voltage check is skipped because
   there is no servo supply yet.
5. **Connect the servo supply** — **power off**, polarity checked twice — to J2,
   with **no servos plugged in**. Switch it on.
6. **Check the protection limits** the board picked for your supply (§4.4):
   ```sh
   python servoctl.py limits
   ```
   A LiPo should show a 6400 mV (2S) or 9600 mV (3S) undervoltage limit marked
   `(auto)`; any other supply shows `undervoltage off`. Set your own with
   `limits <mA> <mV>` if you want one.
7. **Zero the current sensor** with nothing drawing current:
   ```sh
   python servoctl.py tare
   ```
8. **Check the rail:**
   ```sh
   python servoctl.py sense
   ```
   Voltage should match your supply, current should be near 0, no faults.
9. **One servo on channel 0**, then:
   ```sh
   python servoctl.py sweep 0 --park
   ```
10. **Full acceptance test**, with one servo on each channel you plan to use:
    ```sh
    python selftest.py --move --rail
    ```

---

## 3. Tooling manual

All host tools live in `tools/`, are plain Python 3, and depend only on
`pyserial`.

```sh
cd tools
pip install -r requirements.txt
```

### 3.1 Finding the board

The board shows up as a serial port:

| OS | Port name |
|---|---|
| Windows 10/11 | `COMn` (Device Manager → Ports) — built-in driver, nothing to install |
| Linux | `/dev/ttyACM0`, `/dev/ttyACM1`, … |
| macOS | `/dev/cu.usbmodem…` |

`servoctl.py ports` lists every serial port and marks the candidates. The tools
auto-detect the board by its USB ID (`1A86:FE0C`) **and** a version handshake,
because that ID is WCH's generic one and other WCH gadgets share it. To skip
auto-detection, pass `--port`:

```sh
python servoctl.py --port COM5 info
python servoctl.py --port /dev/ttyACM0 info
```

On Linux, add yourself to the `dialout` group once (`sudo usermod -aG dialout
$USER`, then log out and in) so you do not need `sudo`.

### 3.1b `servogui.py` — desktop GUI

```sh
python tools/servogui.py              # auto-detect;  --port COM52  /  --mock
```

**Channels (left).** Tick **on** to drive a channel, drag the slider to move it.
**Enable all** turns on every servo channel at its slider position. **STOP**,
the **space bar** or **Esc** is the panic stop (`X`). The **⚙** button per row sets:

| Setting | What it does |
|---|---|
| Name | shown in the row, poses and CSV headers |
| Min / Max | travel limits in µs — the slider cannot go past them. Set them just inside the servo's mechanical end stops: a servo pushing against a stop stalls and draws its full stall current (~2.3 A for an MG995) |
| Speed | µs per second, 0 = instant. Ramping is done by the GUI in 50 ms steps, so moves are smooth and current spikes smaller |
| Mode | **servo**, or **input** (channels 0–7): the row becomes a live analog bar, 0–4095 counts / 0–3.3 V, and the channel is never driven |

**Rail tab.** Live current and voltage, a 10 s current graph with peak hold,
**Clear faults**, **Tare**, the **Protection** limits (`P`; offered up to
7500 mA — the board's continuous budget is ~5 A (§1.4), its narrowest rail trace
7.8 A; they reset to 5000 mA at power-up), and **Record CSV**, which logs
current, voltage, faults, every channel's pulse width and the analog inputs every
50 ms.

**Poses & sequence tab.** **Save current** stores every channel that is on as a
named pose; **Go to** (or double-click) moves back to it. A sequence is a list of
poses, each with a **move** time (how long to get there; 0 = each channel's own
speed) and a **hold** time. **Play** runs it **repeat** times (0 = forever; the same count goes into a board script uploaded with **Upload sequence**); STOP
or a fault ends it. This is the replacement for the Maestro's sequencer.

**Script tab.** A text editor for board scripts (§3.1c) with syntax colouring:
**Check (F5)** compiles and shows the instruction listing, or marks the bad line
in red; **Upload** / **Upload + Run** store it on the board (with **autorun at
power-up** if ticked); **Run** / **Stop** control the stored script; **Read from
board** turns the stored script back into editable text; **From sequence**
starts from the Poses tab's sequence; **Help** lists every statement.
New / Open / Save / Save as work on `.txt` files (Ctrl+S saves). The editor
text is kept between runs even if unsaved. Space typed in the editor does not
stop the servos; **Esc** always does.

**Firmware tab.** **Flash firmware** runs `flash.py` on the chosen application
image and shows its output — no jumper — then reconnects (§4.7). Build the image
first with `make`.

Settings, poses and the sequence are saved in `tools/servogui.json`. A latched
fault drops every channel; the GUI shows it and **Clear faults** re-arms. Uses
only tkinter (bundled with Python) and pyserial.

### 3.1c `servoscript.py` — scripts that run on the board, without a PC

The firmware has a small script engine. A script is compiled on the PC, stored
in the last 4 KB of flash, and run by the board itself — it keeps going with
the USB cable unplugged, and with **autorun** it starts at every power-up.
Up to 254 instructions; timing comes from the servo timer, to 1 ms.

```sh
python tools/servoscript.py check  tools/examples/wave.txt        # compile, list
python tools/servoscript.py upload tools/examples/wave.txt --run  # store + start
python tools/servoscript.py upload wave.txt --autorun             # start at power-up
python tools/servoscript.py status | run | stop | dump
python tools/servoscript.py from-gui -o seq.txt                   # GUI sequence -> script
```

| Statement | Meaning |
|---|---|
| `name:` | a label, target of `loop` / `jump` |
| `move <ch> <us> [<time>]` | ramp to `<us>` over `<time>` (default 0 = jump). Does **not** wait: moves on *different* channels run together. A second move of the *same* channel first waits for the one before (the compiler adds a `sync` and says so). A channel that is off ramps from where it was last driven (1500 µs if never), over the full time |
| `pose <name> [<time>]` | move every channel of a GUI pose |
| `sync` | wait until every move has **arrived** (`wait` just pauses; `sync` waits for the servos) |
| `wait <time>` / `sleep <time>` | pause for a fixed time. **A plain number is milliseconds** (`2` = 2 ms): write `2s`, `1.5s` or `2000` |
| `off <ch>` / `off all` | stop driving (the servo goes limp). A channel still moving finishes its move first |
| `loop <label> [<n>]` | go back to `<label>`; the block runs `n` times in total, forever without `n` |
| `jump <label>` | go to `<label>` |
| `waitin <ch> > <v>` / `< <v>` | wait for analog input `ch` (0–7) to go above / below `v` (0–4095) |
| `ifin <ch> > <v>` / `< <v>` | run the next statement only if the condition holds |
| `end` | stop; moves still running finish first, then servos hold (same at the end of the script) |

Channels are numbers or the names set in the GUI, and positions are clamped to
each channel's GUI limits, with a warning. A latched rail fault or `X` stops a
running script. The LED blinks four times faster while a script runs. The GUI's
**Poses & sequence** tab can upload its sequence (or a script file) to the board
and run or stop it; the MCP server can too. Pose names used in scripts cannot
contain spaces (the GUI now saves them with underscores).

**Standalone:** fit **JP1** so the logic runs from the servo supply, upload with
`--autorun`, unplug USB — the script starts whenever the servo supply comes on.

### 3.1d `servo_mcp.py` — AI agent control (MCP)

An MCP server that lets an AI agent drive the board through typed tools
instead of shell commands. Install the dependency and register it with your MCP
client as a stdio server:

```sh
pip install "mcp>=2"
python tools/servo_mcp.py        # the command to register; optional: --port COM52
```

Tools: `board_status`, `move_servos` (ramped, waits for arrival, reports peak
current), `disable_servos`, `stop_all`, `list_poses`, `go_to_pose`,
`play_sequence`, `read_analog`, `measure_current`, `set_protection`,
`clear_faults`, `upload_script`, `script_status`, `run_script`, `stop_script`,
`release_port`.

Guardrails: positions are clamped to the GUI's per-channel limits, input-mode
channels are never driven, the overcurrent limit is capped at 7500 mA, a fault
stops everything and is reported, and everything stops when the server exits.
The port is opened on demand and released after 15 s idle (servos keep holding),
so the GUI and `flash.py` can use the board in between — but only one program
can hold the port at a time.

### 3.2 `servoctl.py` — command-line control

General form: `python servoctl.py [--port P] [--mock] [--timeout S] <command> …`

| Command | What it does |
|---|---|
| `ports` | list serial ports, mark candidates |
| `info` | firmware version, every channel's state, rail status |
| `set <ch> <µs>` | set a channel's pulse width, within its travel limits (500–2500 by default). **Also switches the channel on.** |
| `get <ch>` | read a channel's pulse width (`0` = off) |
| `enable <ch>` / `disable <ch>` | switch a channel's output on / off, keeping its last width |
| `center` | set **every** channel to 1500 µs — switches all 12 on |
| `stop` | panic stop: every channel off |
| `sweep <ch>` | walk a channel back and forth. Options: `--low 1000 --high 2000 --step 10 --delay 0.02 --cycles 1 --park` |
| `analog <ch>` | read channel 0–7 as an analog input (0–4095) |
| `sense` | one reading: faults, current (mA), voltage (mV), rail present |
| `monitor` | repeat `sense` until Ctrl-C. Options: `--interval 0.5`, `--stop-on-fault` |
| `tare` | zero the current sensor — switches all channels off first |
| `limits` | show the protection limits in force, and whether undervoltage is automatic |
| `limits <mA> <mV>` | set overcurrent and undervoltage trip levels; `0` disables either. Switches undervoltage to manual until the next power-up |
| `clear` | clear latched faults |
| `boot` | restart into the USB bootloader and stay there (`flash.py` does this itself, §4.7) |
| `raw "<line>"` | send one literal protocol line, print the reply |
| `repl` | interactive session — type protocol commands directly |

Examples:

```sh
python servoctl.py info
python servoctl.py set 3 1200            # channel 3 to 1200 µs
python servoctl.py sweep 0 --low 900 --high 2100 --cycles 3 --park
python servoctl.py monitor --interval 0.2 --stop-on-fault
python servoctl.py raw "S 0 1500"
python servoctl.py stop
```

> **Note on `set`.** There is no "set target but stay off" — setting a pulse
> width is what energises the servo. Use `enable`/`disable` to toggle a channel
> without losing its position.

### 3.3 Any serial terminal works too

The protocol is plain text, so you can type at the board from any terminal set
to the board's port (baud rate is ignored):

```sh
python -m serial.tools.miniterm COM5 115200 --eol LF
```

PuTTY, Tera Term, `screen /dev/ttyACM0` and the Arduino serial monitor all work;
set the line ending to **LF** (or CR+LF). See §4.3 for the commands.

### 3.4 `selftest.py` — acceptance test

```sh
python selftest.py                  # safe checks only, nothing moves
python selftest.py --rail           # a servo supply is connected; check its voltage too
python selftest.py --move --rail    # also move each servo in turn
```

| Option | Meaning |
|---|---|
| `--port P` | serial port; default auto-detect |
| `--move` | run the tests that move servos, one channel at a time |
| `--rail` | a servo supply is on J2; check its voltage is plausible (5–9 V) |
| `--dwell S` | seconds to hold each test position (default 0.4) |
| `--mock` | run against the emulator, no hardware |

What it checks, in order: identity → all channels off at boot → error handling →
rail sensing → analog inputs → movement (`--move`) → current sensing sees a load
→ panic stop. It **always** finishes with a panic stop, even on failure or
Ctrl-C, and exits **0** on pass, **1** on any failure — usable as a production
go/no-go test.

> The `--rail` voltage check expects **5–9 V**. A 3S pack (11.1 V) will fail it
> on purpose; drop `--rail` if that is your supply.

> Firmware older than **0.3** fails the check *"no faults latched at power-on"*
> on any supply below 6 V, because its fixed 6.0 V undervoltage default trips
> first — and it fails *"L reports the limits in force"*, because it has no `L`
> command. Flash 0.3 or later (§4.7).

### 3.5 `usc.py` — Python library

For your own scripts. One class, one method per command:

```python
import sys
sys.path.insert(0, "path/to/tools")
from usc import ServoController, DeviceError

with ServoController.open() as dev:          # or .open("COM5"), or .mock()
    print(dev.version())
    dev.set_limits(5000, 5000)                # suit a 6 V supply
    dev.clear_faults()
    dev.tare()

    dev.set_us(0, 1500)                       # also enables channel 0
    dev.set_us(1, 1000)
    print(dev.positions())                    # [1500, 1000, 0, 0, ...]

    st = dev.status()                         # Status(faults, current_ma, voltage_mv, rail_present)
    print(st, st.ok, st.fault_names)

    try:
        dev.set_us(2, 1500)
    except DeviceError as e:
        print("refused:", e.reason)           # e.g. 'fault'

    dev.stop_all()
```

| Method | Protocol | Returns |
|---|---|---|
| `version()` | `V` | str |
| `travel(ch)` / `set_travel(ch, min, max)` | `R` | (min, max) / — |
| `save_settings()` / `reset_settings()` | `W` / `W D` | — |
| `set_us(ch, us)` | `S` | — |
| `get_us(ch)` | `G` | int, 0 = off |
| `enable(ch, on=True)` / `disable(ch)` | `E` | — |
| `stop_all()` | `X` | — |
| `read_analog(ch)` | `A` | int 0–4095 |
| `current_ma()` / `voltage_mv()` | `I` / `U` | int |
| `read_raw(0 \| 1)` | `N` | int counts |
| `tare()` | `Z` | int offset |
| `status()` | `F` | `Status` |
| `clear_faults()` | `C` | — |
| `limits()` | `L` | `Limits(overcurrent_ma, undervoltage_mv, auto)` |
| `set_limits(mA, mV)` | `P` | — |
| `reboot_to_bootloader()` | `BOOT` | str |
| `command("…")` | anything | raw reply str |
| `center_all()`, `positions()`, `sweep(...)`, `watch()` | built on the above | |

Errors: `DeviceError` (board said `ERR …`; `.reason` holds the word),
`ProtocolError` (unexpected or missing reply), `NotFoundError` (no board found).
All derive from `UscError`.

### 3.6 Working without hardware

Every tool accepts `--mock`, and the library has `ServoController.mock()`. This
runs an in-process emulator of the firmware's command parser, so you can write
and test host code before a board exists. It simulates 12 mA idle plus 120 mA per
enabled channel on a 7.94 V rail. It has no timers, no USB and no ADC noise — it
proves your code, not the board.

### 3.7 Existing Maestro software

From firmware **0.4** the board speaks the Maestro *serial* protocols (§4.3b),
so community libraries work unchanged: point them at the board's COM port.
Tested with [FRC4564/Maestro](https://github.com/FRC4564/Maestro):

```python
import maestro
m = maestro.Controller("COM52")      # /dev/ttyACM0 on Linux
m.setSpeed(0, 20)                    # 0.25 us per 10 ms units: 500 us/s
m.setTarget(0, 8000)                 # quarter-microseconds: 2000 us
```

Pololu's Maestro Control Center and `UscCmd` **cannot** talk to this board —
they require Pololu's own USB vendor ID. Use `servogui.py` instead. That
library's `getMovingState()` always returns True on Python 3 (a bytes/str
comparison bug in the library); `isMoving(ch)` works.

---

## 4. Embedded manual

### 4.1 Firmware behaviour at a glance

| | |
|---|---|
| Version string | `USBServoController 0.4 12ch CH32V203 isense maestro` |
| Clock | 8 MHz crystal × 12 = 96 MHz; USB 48 MHz |
| Servo frame | 20 ms (50 Hz), all channels |
| Pulse range | per channel, 500–2500 µs by default, settable 64–4080 µs (`R`); neutral 1500 |
| Resolution | 0.5 µs (Maestro targets use it; ASCII `S` takes whole µs) |
| At power-up | **every channel off (output held low)** — nothing moves until commanded |
| Settings storage | travel limits and Maestro start-up speed/acceleration, saved with `W` (survive power-off and firmware updates); protection limits, zero-offset and positions are not stored |
| Rail monitoring | every ~10 ms, starting 250 ms after power-up |
| Protection trip | 5 consecutive out-of-limit readings (~50 ms) → all channels off, fault latched |

### 4.2 Protocol basics

- Text lines, terminated with `\n` (`\r` is ignored). Max 63 characters.
- Command letters are case-insensitive; fields separated by spaces.
- **Exactly one reply per command line**, ending `\r\n`:
  - `OK` — done
  - `OK <value>` — done, here is the value
  - `ERR <reason>` — refused
- Send the next command after reading the reply.

### 4.3 Command reference

**Servo control**

| Command | Reply | Meaning |
|---|---|---|
| `S <ch> <us>` | `OK` | set pulse width within the channel's travel limits **and switch the channel on** |
| `G <ch>` | `OK <us>` | pulse width, `0` if the channel is off |
| `E <ch> 1` | `OK` | switch channel on at its last width (1500 if never set) |
| `E <ch> 0` | `OK` | switch channel off (output low, servo goes limp) |
| `X` | `OK` | **panic stop** — every channel off |
| `A <ch>` | `OK <counts>` | read channel 0–7 as analog, 0–4095 over 0–3.3 V |

**Stored script** (`servoscript.py` drives these; format in `User/script.h`)

| Command | Reply | Meaning |
|---|---|---|
| `QC` | `OK` | clear the RAM upload buffer |
| `QA <i> <op> <ch> <a> <b>` | `OK` | put instruction `i` in the buffer (validated) |
| `QS <count> <flags>` | `OK <crc>` | save the buffer to flash; flags bit 0 = autorun |
| `QI` | `OK <valid> <count> <flags> <state> <pc>` | stored script; state 0 idle, 1 running, 2 done, 3 faulted |
| `QG <i>` | `OK <op> <ch> <a> <b>` | read instruction `i` back from flash |
| `QR` / `QX` | `OK` | run from the top / stop (servos hold). `X` and a rail fault also stop it |

**Servo-rail monitoring**

| Command | Reply | Meaning |
|---|---|---|
| `I` | `OK <mA>` | servo-rail current |
| `U` | `OK <mV>` | servo-rail voltage |
| `F` | `OK <faults> <mA> <mV> <present>` | status: fault bits, last current, last voltage, rail present (1/0) |
| `L` | `OK <mA> <mV> <auto>` | limits in force; `auto` = 1 while the undervoltage limit is chosen automatically. `<mV>` is `0` when no cutoff applies |
| `P <mA> <mV>` | `OK` | set overcurrent / undervoltage limits; `0` disables either. Leaves auto mode until the next power-up |
| `C` | `OK` | clear latched faults |
| `Z` | `OK <counts>` | zero the current sensor (switches all channels off first) |
| `N 0` / `N 1` | `OK <counts>` | raw ADC counts: 0 = current, 1 = voltage |

**System**

| Command | Reply | Meaning |
|---|---|---|
| `V` | version string | note: **no** `OK` prefix |
| `R <ch>` | `OK <min> <max>` | the channel's travel limits, µs |
| `R <ch> <min> <max>` | `OK` | set them, 64 ≤ min < max ≤ 4080. Every `S`, script move and Maestro target is clamped to them; a running channel outside is pulled inside at once. In RAM until `W` |
| `W` | `OK` | save travel limits and Maestro speed/acceleration to flash, loaded at every power-up |
| `W D` | `OK` | factory defaults (500–2500 µs, speed/accel 0) in RAM and flash |
| `BOOT` | `OK BOOT` | reset into the board's USB bootloader; the port drops and returns as the bootloader (§4.7). |

**Error reasons**

| `ERR …` | Cause |
|---|---|
| `syntax` | missing or non-numeric argument |
| `channel` | channel number above 11 |
| `range` | pulse outside the channel's travel limits, or `R` limits outside 64–4080 / min ≥ max |
| `fault` | a rail fault is latched — `S` and `E … 1` are refused until `C` |
| `flash` | `W` could not write or verify the settings page |
| `noanalog` | `A` on channel 8–11 (no analog path) |
| `index` | `N` with an index other than 0 or 1 |
| `adc` | ADC conversion timed out |
| `unknown` | unrecognised command letter |
| `toolong` | line longer than 63 characters |

Example session:

```
> V
USBServoController 0.4 12ch CH32V203 isense maestro
> L
OK 5000 0 1            <- 6 V BEC detected: no undervoltage cutoff, auto mode
> S 0 1500
OK
> F
OK 0 142 5980 1        <- no faults, 142 mA, 5.98 V, rail present
> X
OK
```

### 4.3b Maestro serial protocols (firmware 0.4+)

Any byte of `0x80` or above starts a Pololu Maestro command; printable ASCII
goes to the text protocol above. Both can be used on the same port. Three
framings, as on a Maestro:

| Framing | Example: channel 0 to 1500 µs |
|---|---|
| Compact | `84 00 70 2E` |
| Pololu, device number 12 | `AA 0C 04 00 70 2E` |
| Mini SSC | `FF 00 7F` (0–254, 127 = 1500 µs, ±476 µs) |

Targets are in **quarter-microseconds** (1500 µs = 6000) sent as two 7-bit
bytes, low first. A target of `0` switches the channel off.

| Compact | Command | Data | Reply |
|---|---|---|---|
| `84` | Set Target | ch, target | — |
| `9F` | Set Multiple Targets | count, first ch, count × target | — |
| `87` | Set Speed | ch, speed in 0.25 µs per 10 ms (0 = unlimited) | — |
| `89` | Set Acceleration | ch, 0–255 in 0.25 µs per 10 ms per 80 ms (0 = unlimited) | — |
| `90` | Get Position | ch | 2 bytes, quarter-µs, low first; 0 = off |
| `93` | Get Moving State | — | 1 byte, 1 while any channel is ramping |
| `A1` | Get Errors | — | 2 bytes, then cleared; `0x0010` = protocol error |
| `A2` | Go Home | — | — (all channels off) |
| `A4` | Stop Script | — | — (stops the board's stored script) |
| `AE` | Get Script Status | — | 1 byte, 0 = running, 1 = stopped |

`8A` Set PWM and `A7`/`A8` Restart Script are accepted and ignored.

How it differs from a Maestro:

- Targets clamp to each channel's **travel limits** (`R`, 500–2500 µs by
  default), as a Maestro clamps to its channel min/max. Output is in 0.5 µs
  steps; Get Position returns the exact target once a move has arrived.
- Speed and acceleration set over the protocol last until power-off. To make
  them the power-up values, send `W` afterwards (a Maestro keeps these in
  Control Center settings).
- An off channel jumps straight to its first target: its position is unknown.
- A latched rail fault (§4.4) blocks Maestro targets like it blocks `S`.
- An ASCII `S`, `E` or `X` on a channel ends any Maestro ramp on it.

### 4.4 Protection: overcurrent and undervoltage

The firmware watches the servo rail and, on a fault, **switches every channel
off** (which makes the servos go limp and stops them drawing current) and
**latches** the fault until you clear it.

| Fault | Bit in `F` | Default limit | Trips when |
|---|---|---|---|
| Overcurrent | `1` | 5000 mA | current above limit for ~50 ms |
| Undervoltage | `2` | **automatic** — see below | voltage below limit for ~50 ms, *and* a supply is present (> 2 V) |

**Automatic undervoltage (the default).** About 100 ms after a servo supply
appears — once the voltage has settled — the firmware picks a cutoff from it:

| Supply voltage when connected | Treated as | Undervoltage cutoff |
|---|---|---|
| below 6.6 V | 5 V / 6 V BEC, 4–5 cell NiMH, bench supply | **none** |
| 6.6–8.8 V | 2S LiPo | **6.4 V** (3.2 V/cell) |
| 8.8–9.9 V | ambiguous (e.g. 7-cell NiMH) | **none** |
| 9.9 V and above | 3S LiPo | **9.6 V** (3.2 V/cell) |

Unplugging the servo supply resets this, so swapping a pack for a different one
is re-detected. Check what was chosen with `L` (`servoctl.py limits`).

Automatic mode cannot tell a **2S pack that is already below 6.6 V** from a
bench supply, so it gives that pack no cutoff — charge packs before use. It also
treats a regulated supply in the 6.6–8.8 V range (for example a 7.4 V HV-servo
BEC) as a 2S pack, which is harmless: a cutoff at 6.4 V only acts if that supply
collapses.

**Manual limits.** `P <mA> <mV>` overrides both limits and switches undervoltage
to manual until the next power-up. Suggestions:

| Servo supply | `P` |
|---|---|
| 4× NiMH, 4.8 V | `P 5000 4200` |
| 5 V BEC / bench supply | `P 5000 4400` |
| 6 V BEC | `P 5000 5000` |
| 2S LiPo (7.4 V) | `P 5000 6400` — same as automatic |
| 3S LiPo (11.1 V) | `P 5000 9600` — same as automatic |

Limits are not stored: after a power-cycle the board is back in automatic mode
with a 5000 mA overcurrent limit. `P 0 0` disables both — only do that on a
bench supply with its own current limit. After changing limits, send `C` to
clear any fault the old limit caused.

**Recovering from a trip:** find and fix the cause (a stalled servo, a flat
battery) → `C` → re-enable channels with `S` or `E`.

> ⚠️ **What undervoltage protection does not do.** It stops the servos, but the
> board itself keeps drawing ~15 mA from the battery if JP1 is fitted. It does
> not disconnect the battery. **Unplug the battery** when the board trips on a
> flat pack, or it will keep discharging.

> The current reading is for the **whole rail**, not per channel. A trip tells
> you *something* drew too much, not which servo.

### 4.5 Accuracy of the readings

- **Current:** about 3.2 mA per count, 0–13.2 A range. Out of the box there is a
  zero offset of a few tens of mA — run `Z` (or `servoctl.py tare`) with nothing
  drawing current after each power-up.
- **Voltage:** about 3.2 mV per count, 0–13.2 V range. Saturates above 13.2 V.
- Both are referenced to the board's 3.3 V regulator (±2–3 %). Good for
  thresholds; not a calibrated meter.

### 4.6 Building the firmware

Source is in `embedded-ch32/`.

**You need:**
- **xPack `riscv-none-elf-gcc`** (tested with 15.2.0) —
  <https://xpack-dev-tools.github.io/riscv-none-elf-gcc-xpack/>
- **GNU make**
- Python 3 (only for the pin-map check)

**Build:**

```sh
cd embedded-ch32
make GCC_PATH=/path/to/xpack-riscv-none-elf-gcc-15.2.0-1/bin
```

Outputs in `embedded-ch32/build/`: `USBServoController-ch32.elf`, `.hex`, `.bin`.
`make clean` removes them; `make size` prints flash/RAM use (~20 KB of 64 KB
flash, ~3 KB of 20 KB RAM).

> Three toolchain traps are already handled in the Makefile and sources — keep
> them if you change toolchain: `-march=rv32imac_zicsr_zifencei`, `-std=gnu11`,
> and every interrupt handler declared `interrupt("machine")`, **never**
> `"WCH-Interrupt-fast"` (upstream GCC silently ignores it and the build links
> but crashes). README §5 explains each.

**Source layout:**

| File | Role |
|---|---|
| `User/main.c` | init, main loop (1 ms tick): protocol, rail monitor, LED |
| `User/servo.c/.h` | 12-channel PWM on TIM1–TIM4, pulse limits, analog reads |
| `User/sense.c/.h` | ADC, current/voltage conversion, fault detection |
| `User/protocol.c/.h` | command parser, replies, bootloader jump |
| `User/cdc_glue.c` | USB CDC line-coding stub |
| `USBLIB/CONFIG/` | USB descriptors and endpoint handling (WCH library, modified) |
| `HAL/`, `Startup/`, `Ld/` | WCH vendor HAL, startup code, linker script |
| `tools/verify_pinmap_ch32.py` | checks schematic ↔ pin table ↔ firmware agree |
| `test/test_sense.c` | runs the real `sense.c` on the PC against a stubbed ADC |

**Changing things:**

| To change | Edit |
|---|---|
| default travel limits (500–2500 µs) | `SERVO_US_MIN` / `SERVO_US_MAX` in `servo.h`; per channel at runtime with `R` |
| frame rate / resolution | `SERVO_TIMER_HZ`, `SERVO_FRAME_TICKS` in `servo.h` (16-bit timer: ticks ≤ 65535) |
| default protection limits | `SENSE_DEFAULT_LIMIT_MA` / `_MV` in `sense.h` |
| trip speed | `SENSE_TRIP_COUNT`, `SENSE_TASK_PERIOD_MS` in `sense.c` |
| add a command | a new `case` in `execute()` in `protocol.c` — and mirror it in `tools/usc.py` (`ServoController` and `MockDevice`) |

After changing anything in `sense.c`, run its host test — it compiles the real
file for the PC and drives it through 21 supply scenarios (any host C compiler;
`HOSTCC="zig cc"` works too):

```sh
make hosttest HOSTCC=gcc
```

After any schematic change, run the cross-check:

```sh
python embedded-ch32/tools/verify_pinmap_ch32.py   # needs KiCad 10's kicad-cli
```

### 4.7 Flashing the firmware — over USB, no programmer

Flash is split in four: a small **USB bootloader** in the first 12 KB, the
**application** from `0x3000` (48 KB), the **stored script** (2 KB from
`0xF000`) and the **settings** page (`0xF800`)
(`embedded-ch32/User/flash_layout.h`). A firmware update keeps the stored
script and the settings — provided the bootloader on the board was built with
this layout (bootloaders from before the script engine erase up to `0xFFFF`;
update it once with the JP2 + `wchisp` full image below). The
bootloader runs on every reset and starts the application at once, unless the
application asked it to stay (`BOOT` command) or there is no valid application.

**Routine update — no jumper, no replug** (board running, USB plugged in):

```sh
cd embedded-ch32
make flash                       # build, then python ../tools/flash.py
```

or `python tools/flash.py [app.bin] [--port COMx]` directly. It sends `BOOT`,
waits for the bootloader (same USB IDs, same COM port — LED blinks fast, 5 Hz),
erases, writes, verifies by CRC-32 and starts the new application: about 3 s.
Page 0 is written last, so if the flash is interrupted the board simply stays in
the bootloader — run `flash.py` again. Give it the **application** image
`build/USBServoController-ch32.bin`, never the `-full.bin`.

**First flash of a blank chip, or recovery — JP2 + ROM bootloader.** The chip
also has WCH's factory USB bootloader in ROM; it installs the bootloader and
application together. No debugger is needed.

1. Install **`wchisp`**: `cargo install wchisp`, or download a release from
   <https://github.com/ch32-rs/wchisp>. (`chprog` or WCH's WCHISPTool also work.)
2. **Unplug USB.** Fit a shunt cap on **JP2**.
3. **Plug in USB.** The LED stays **off**; the board appears as USB device
   `4348:55e0` (the WCH bootloader), not as a serial port.
4. Check it is seen, then flash:
   ```sh
   wchisp info
   make full                     # in embedded-ch32/
   wchisp flash embedded-ch32/build/USBServoController-ch32-full.bin
   ```
5. **Unplug USB, remove the JP2 cap**, plug back in. The LED blinks, and
   `servoctl.py info` shows the version.

> **Windows:** if `wchisp info` cannot find the device, the bootloader needs the
> WinUSB driver. Run [Zadig](https://zadig.akeo.ie/), select the device with ID
> `4348 55E0`, and install **WinUSB**. This is needed once per PC and does not
> affect the board's normal serial port.

A blank board from the factory has no firmware at all, so steps 2–5 are how
every new board gets programmed the first time. After that, use `flash.py`.

**Debugging (optional):** fit a 1×5 header on J9 and connect a **WCH-LinkE**
(3V3, DIO, CLK, GND; RST optional). Use MounRiver Studio, WCH-LinkUtility or
OpenOCD from WCH's toolchain. An ST-Link will not work (§1.8).

---

## 5. Troubleshooting

| Symptom | Likely cause | Fix |
|---|---|---|
| LED dark, USB plugged in | JP2 fitted → ROM bootloader; or no firmware yet | remove JP2 and re-plug; or flash (§4.7) |
| LED blinking fast (5 Hz) | in the USB bootloader: after `BOOT`, an interrupted flash, or no valid application | run `python tools/flash.py` |
| No serial port appears | charge-only USB cable; board in bootloader mode | use a data cable; check JP2 |
| `servoctl` finds no board | another program has the port open; Linux permissions | close serial monitors; join `dialout`; try `--port` |
| Linux: port vanishes / garbled for a few seconds after plug-in | ModemManager probing the port | `sudo systemctl stop ModemManager`, or add a udev rule to ignore `1a86:fe0c` |
| Every `S` or `E` gives `ERR fault` | a fault latched — a flat pack, a stalled servo, or (firmware older than 0.3) the old fixed 6 V undervoltage default on a 5–6 V supply | `servoctl.py sense` to see which; fix the cause, or set `limits` (§4.4); `clear`. Update old firmware (§4.7) |
| Servos twitch or reset when several move | supply cannot deliver the current, or wires too thin | stronger supply, thicker J2 wiring, shorter leads |
| Servos do nothing, commands reply `OK` | no servo supply on J2 (USB never powers servos) | `sense` — `rail present` must be 1 |
| One servo does nothing | plug reversed, or wrong row | dark wire toward the bottom edge (§1.3) |
| Trips overcurrent when servos start | inrush from many servos at once | move them in turn, or raise the limit with `P` |
| Current reads a few tens of mA with everything off | sensor zero offset | `tare` after each power-up |
| Voltage reads ~13200 and never changes | supply above 13.2 V — reading saturated | use a lower-voltage supply (§1.4) |
| `A` on ch 8–11 gives `ERR noanalog` | those channels have no analog input | use channels 0–7 |
| `wchisp` cannot see the board | JP2 not fitted at power-up; Windows driver | fit JP2 *before* plugging in; Zadig → WinUSB |
| Board still in bootloader after flashing | JP2 still fitted | remove it, re-plug |

---

## 6. Quick reference card

```
WIRING    servo plug: signal toward the chip, dark wire toward the board edge
          J2: lower screw +, upper screw −   (NO reverse protection)
          servo supply ≤ 16 V absolute, ≤ 13.2 V to read correctly, ≈ 5 A total
          USB never powers the servos

JUMPERS   JP1 fitted  = logic may run from the servo supply
          JP2 fitted  = ROM bootloader at power-up (blank chip / recovery only)

EVERY POWER-UP
          L             check limits: LiPo 2S/3S get an automatic cutoff,
                        other supplies get none unless you set one with P
          Z             zero the current sensor, nothing running

COMMANDS  S ch us   set + enable     G ch    read (0 = off)
          E ch 0|1  off / on         X       PANIC STOP
          A ch      analog, ch 0–7   V       version
          I  U  F   current / voltage / status
          L         show limits      P mA mV set limits (manual)
          C         clear faults     Z       tare

TOOLS     python servoctl.py info | set 0 1500 | sweep 0 --park | monitor | stop
          python selftest.py [--rail] [--move]
          add --mock to run anything without hardware

FLASH     make flash            (or python tools/flash.py) — no jumper
          blank chip: JP2 on → plug → wchisp flash build/…-full.bin
                      → unplug → JP2 off → plug
```

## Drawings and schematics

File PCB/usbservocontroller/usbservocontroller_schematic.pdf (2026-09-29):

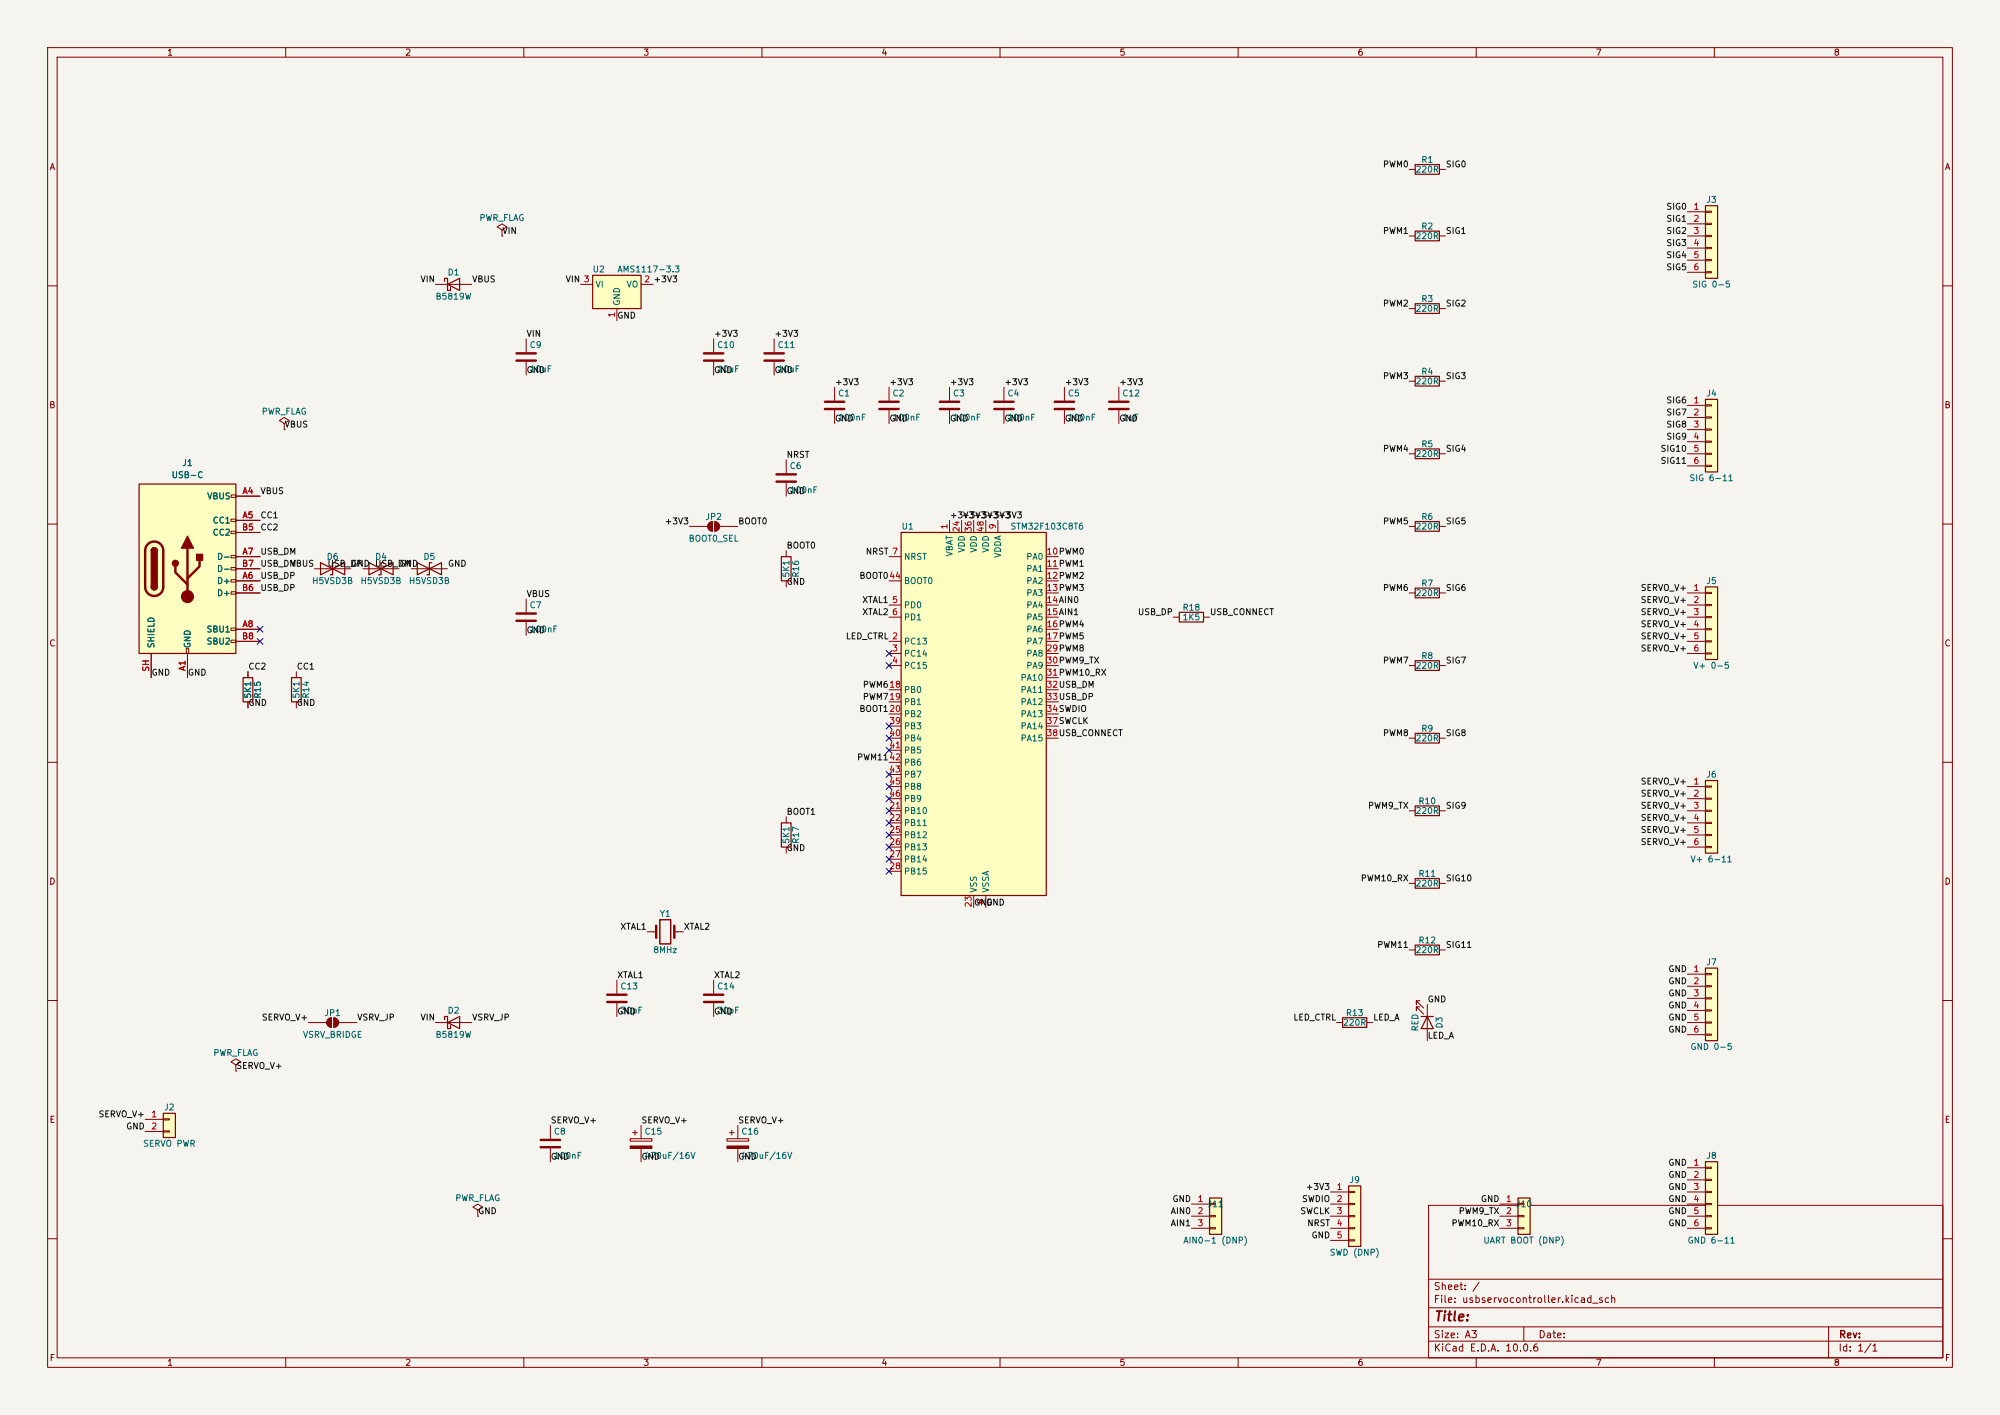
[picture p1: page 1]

Size: A3 | Rev: | F Date:
KiCad E.D.A. 10.0.6 | Id: 1/1

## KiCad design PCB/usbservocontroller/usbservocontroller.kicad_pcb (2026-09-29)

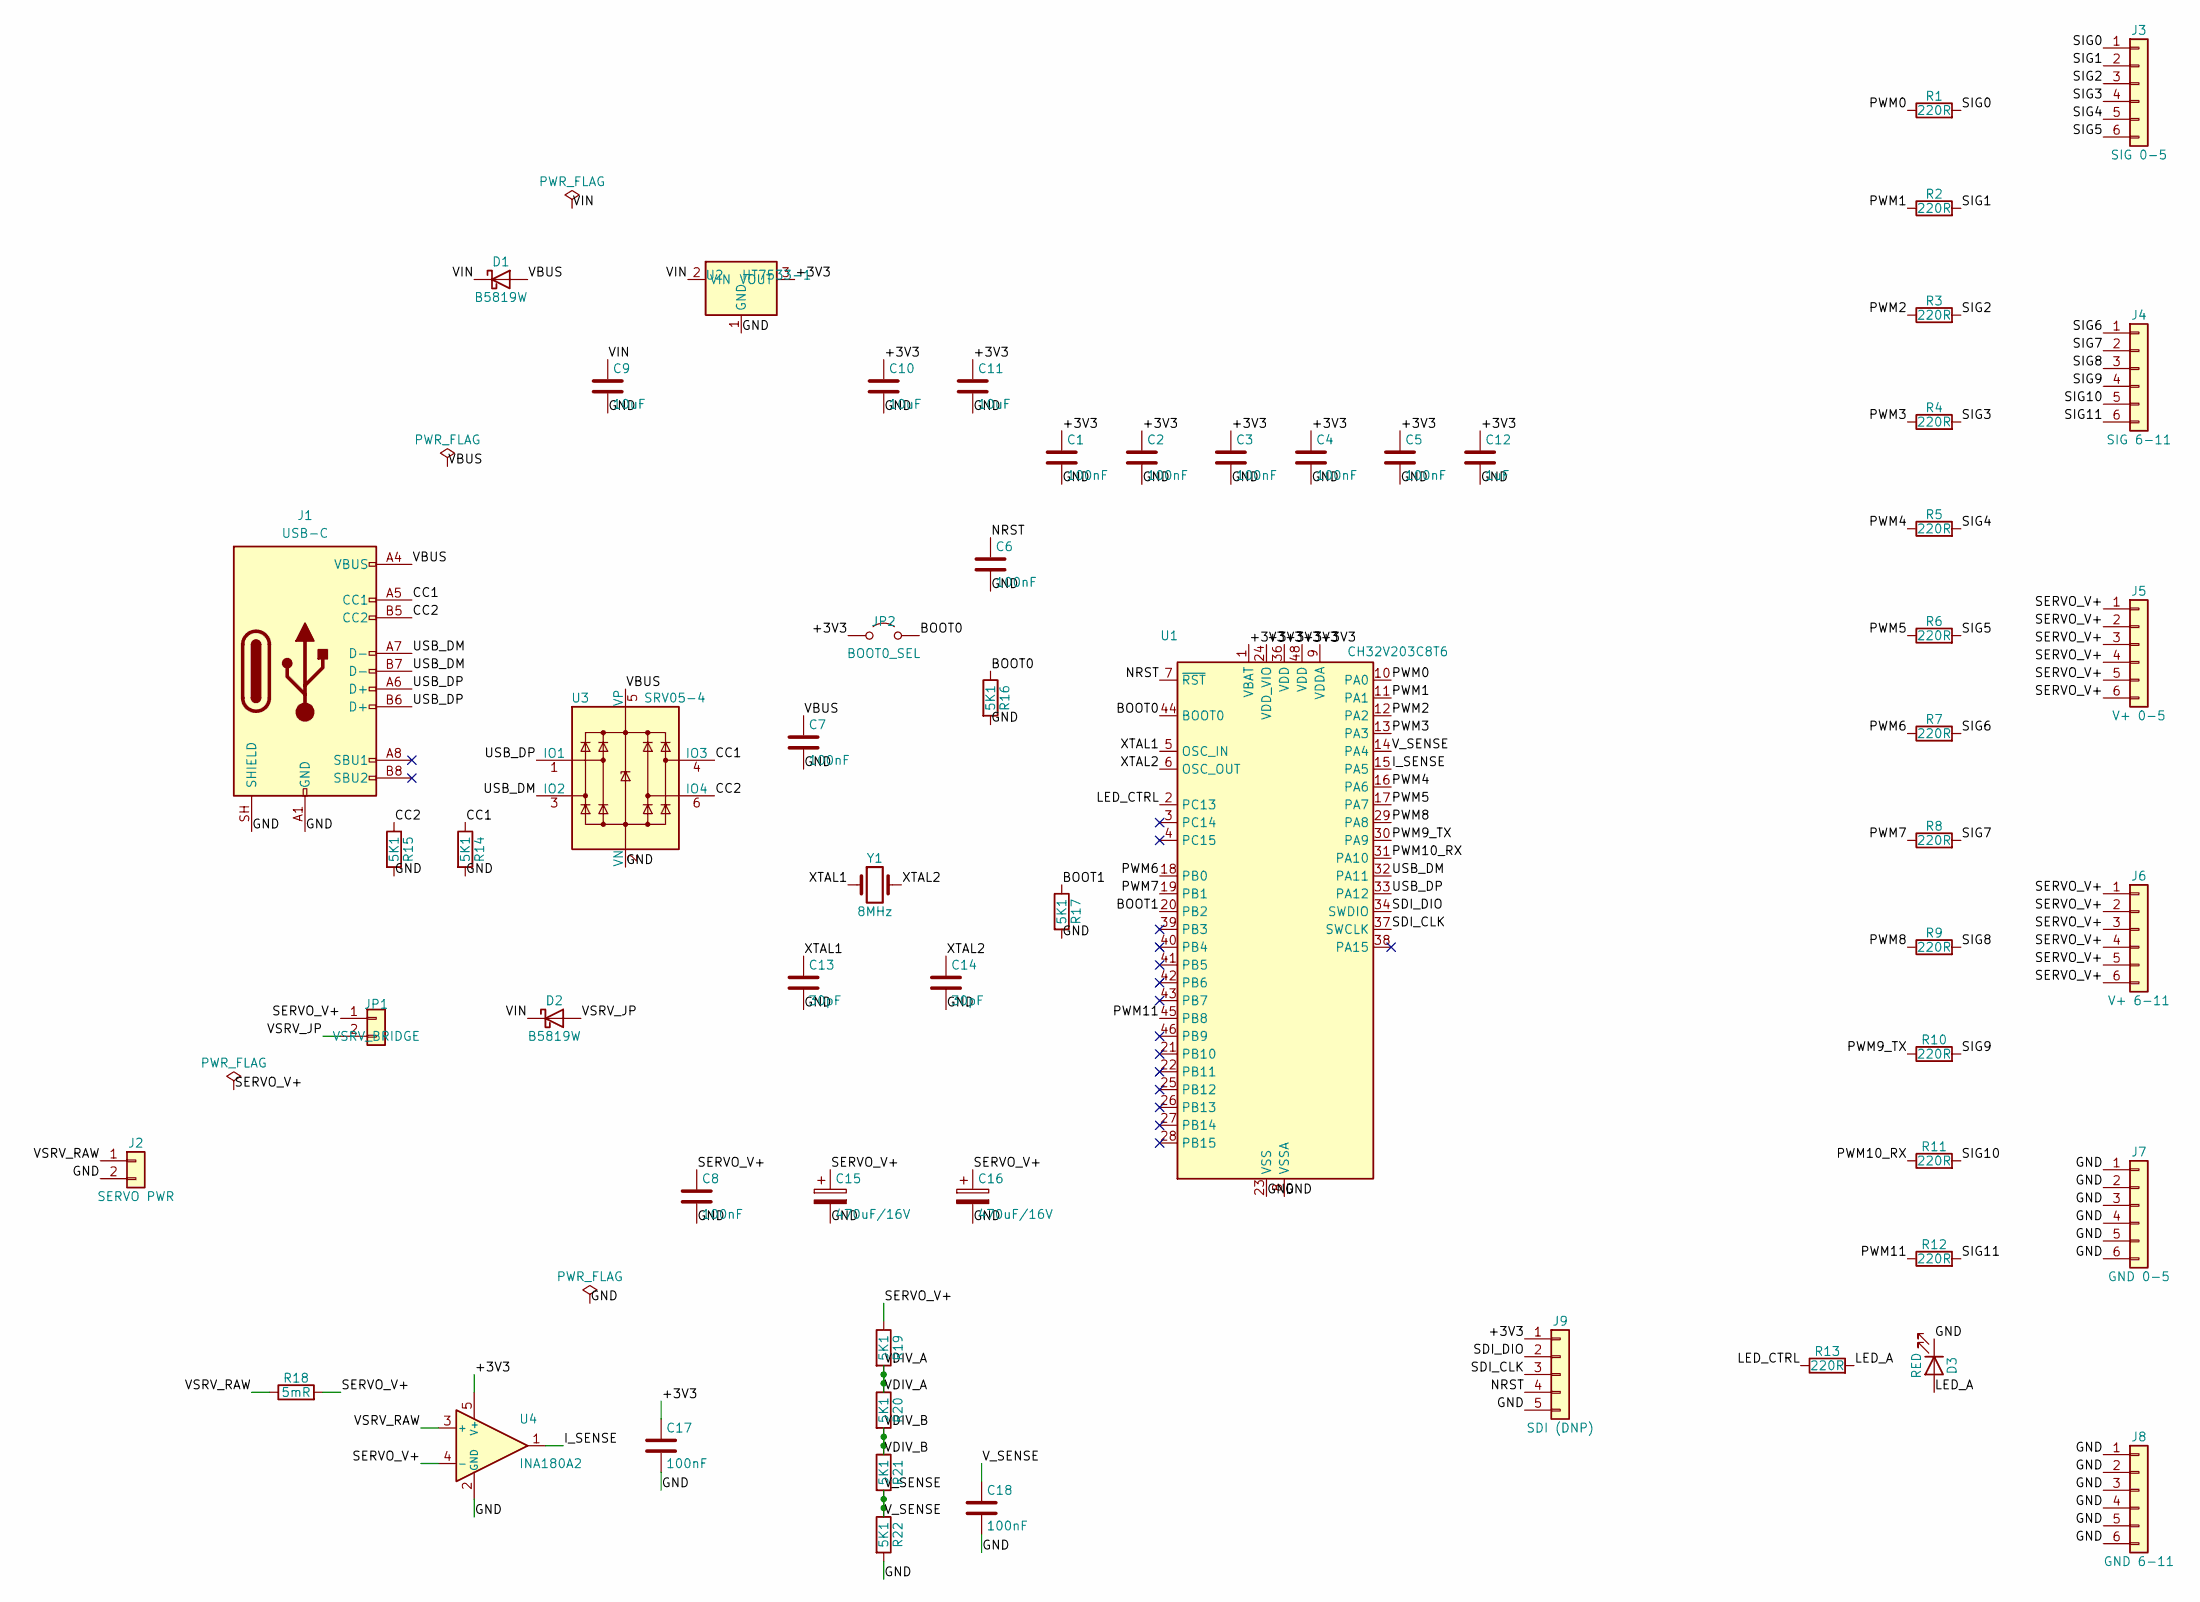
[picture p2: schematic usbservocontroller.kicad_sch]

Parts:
C1, C2, C3, C4, C5, C6, C7, C8, C17, C18: 100nF; C_0603_1608Metric; LCSC C14663
C9, C10, C11: 10uF; C_0603_1608Metric; LCSC C19702
C12: 1uF; C_0603_1608Metric; LCSC C15849
C13, C14: 30pF; C_0603_1608Metric; LCSC C1658
C15, C16: 470uF/16V; CP_Elec_6.3x7.7; LCSC C46550400
D1, D2: B5819W; D_SOD-123; LCSC C7420330
D3: RED; LED_0603_1608Metric; LCSC C2286
J1: USB-C; USB_C_Receptacle_HRO_TYPE-C-31-M-12; LCSC C165948
J2: SERVO PWR; TerminalBlock_RND_205-00232_1x02_P5.08mm_Horizontal; LCSC C474952
J3: SIG 0-5; PinHeader_1x06_P2.54mm_Vertical; LCSC C37208
J4: SIG 6-11; PinHeader_1x06_P2.54mm_Vertical; LCSC C37208
J5: V+ 0-5; PinHeader_1x06_P2.54mm_Vertical; LCSC C37208
J6: V+ 6-11; PinHeader_1x06_P2.54mm_Vertical; LCSC C37208
J7: GND 0-5; PinHeader_1x06_P2.54mm_Vertical; LCSC C37208
J8: GND 6-11; PinHeader_1x06_P2.54mm_Vertical; LCSC C37208
J9: SDI (DNP); PinHeader_1x05_P2.54mm_Vertical
JP1: VSRV_BRIDGE; PinHeader_1x02_P2.54mm_Vertical; LCSC C358684
JP2: BOOT0_SEL; PinHeader_1x02_P2.54mm_Vertical; LCSC C358684
R1, R2, R3, R4, R5, R6, R7, R8, R9, R10, R11, R12, R13: 220R; R_0603_1608Metric; LCSC C22962
R14, R15, R16, R17, R19, R20, R21, R22: 5K1; R_0603_1608Metric; LCSC C23186
R18: 5mR; R_1206_3216Metric; LCSC C7419996
U1: CH32V203C8T6; LQFP-48_7x7mm_P0.5mm; LCSC C3001172
U2: HT7533-1; SOT-89-3_RectTab; LCSC C14289
U3: SRV05-4; SOT-23-6; LCSC C558418
U4: INA180A2; SOT-23-5; LCSC C192764
Y1: 8MHz; Crystal_SMD_5032-2Pin_5.0x3.2mm; LCSC C115962

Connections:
/+3V3: C1.1, C2.1, C3.1, C4.1, C5.1, C10.1, C11.1, C12.1, C17.1, J9.1, JP2.1 (A), U1.1 (VBAT), U1.9 (VDDA), U1.24 (VDD_VIO), U1.36 (VDD), U1.48 (VDD), U2.3 (VOUT), U4.5 (V+); also elsewhere on the board
/BOOT0: JP2.2 (B), R16.1, U1.44 (BOOT0); also elsewhere on the board
/BOOT1: R17.1, U1.20 (PB2)
/CC1: J1.A5 (CC1), R14.1, U3.4 (IO3)
/CC2: J1.B5 (CC2), R15.1, U3.6 (IO4)
/GND: C1.2, C2.2, C3.2, C4.2, C5.2, C6.2, C7.2, C8.2, C9.2, C10.2, C11.2, C12.2, C13.2, C14.2, C15.2, C16.2, C17.2, C18.2, D3.1 (K), J1.A1 (GND), J1.A12 (GND), J1.B1 (GND), J1.B12 (GND), J1.SH (SHIELD), J2.2, J7.1, J7.2, J7.3, J7.4, J7.5, J7.6, J8.1, J8.2, J8.3, J8.4, J8.5, J8.6, J9.5, R14.2, R15.2, R16.2, R17.2, R22.2, U1.8 (VSSA), U1.23 (VSS), U1.35 (VSS), U1.47 (VSS), U2.1 (GND), U3.2 (VN), U4.2 (GND)
/I_SENSE: U1.15 (PA5), U4.1
/LED_A: D3.2 (A), R13.2
/LED_CTRL: R13.1, U1.2 (PC13)
/NRST: C6.1, J9.4, U1.7 (~RST)
/PWM0: R1.1, U1.10 (PA0)
/PWM1: R2.1, U1.11 (PA1)
/PWM2: R3.1, U1.12 (PA2)
/PWM3: R4.1, U1.13 (PA3)
/PWM4: R5.1, U1.16 (PA6)
/PWM5: R6.1, U1.17 (PA7)
/PWM6: R7.1, U1.18 (PB0)
/PWM7: R8.1, U1.19 (PB1)
/PWM8: R9.1, U1.29 (PA8)
/PWM9_TX: R10.1, U1.30 (PA9)
/PWM10_RX: R11.1, U1.31 (PA10)
/PWM11: R12.1, U1.45 (PB8)
/SDI_CLK: J9.3, U1.37 (SWCLK)
/SDI_DIO: J9.2, U1.34 (SWDIO)
/SERVO_V+: C8.1, C15.1, C16.1, J5.1, J5.2, J5.3, J5.4, J5.5, J5.6, J6.1, J6.2, J6.3, J6.4, J6.5, J6.6, JP1.1, R18.2, R19.1, U4.4 (-)
/SIG0: J3.1, R1.2
/SIG1: J3.2, R2.2
/SIG2: J3.3, R3.2
/SIG3: J3.4, R4.2
/SIG4: J3.5, R5.2
/SIG5: J3.6, R6.2
/SIG6: J4.1, R7.2
/SIG7: J4.2, R8.2
/SIG8: J4.3, R9.2
/SIG9: J4.4, R10.2
/SIG10: J4.5, R11.2
/SIG11: J4.6, R12.2
/USB_DM: J1.A7 (D-), J1.B7 (D-), U1.32 (PA11), U3.3 (IO2)
/USB_DP: J1.A6 (D+), J1.B6 (D+), U1.33 (PA12), U3.1 (IO1)
/VBUS: C7.1, D1.2 (A), J1.A4 (VBUS), J1.A9 (VBUS), J1.B4 (VBUS), J1.B9 (VBUS), U3.5 (VP)
/VDIV_A: R19.2, R20.1
/VDIV_B: R20.2, R21.1
/VIN: C9.1, D1.1 (K), D2.1 (K), U2.2 (VIN)
/VSRV_JP: D2.2 (A), JP1.2
/VSRV_RAW: J2.1, R18.1, U4.3 (+)
/V_SENSE: C18.1, R21.2, R22.1, U1.14 (PA4)
/XTAL1: C13.1, U1.5 (OSC_IN), Y1.1
/XTAL2: C14.1, U1.6 (OSC_OUT), Y1.2

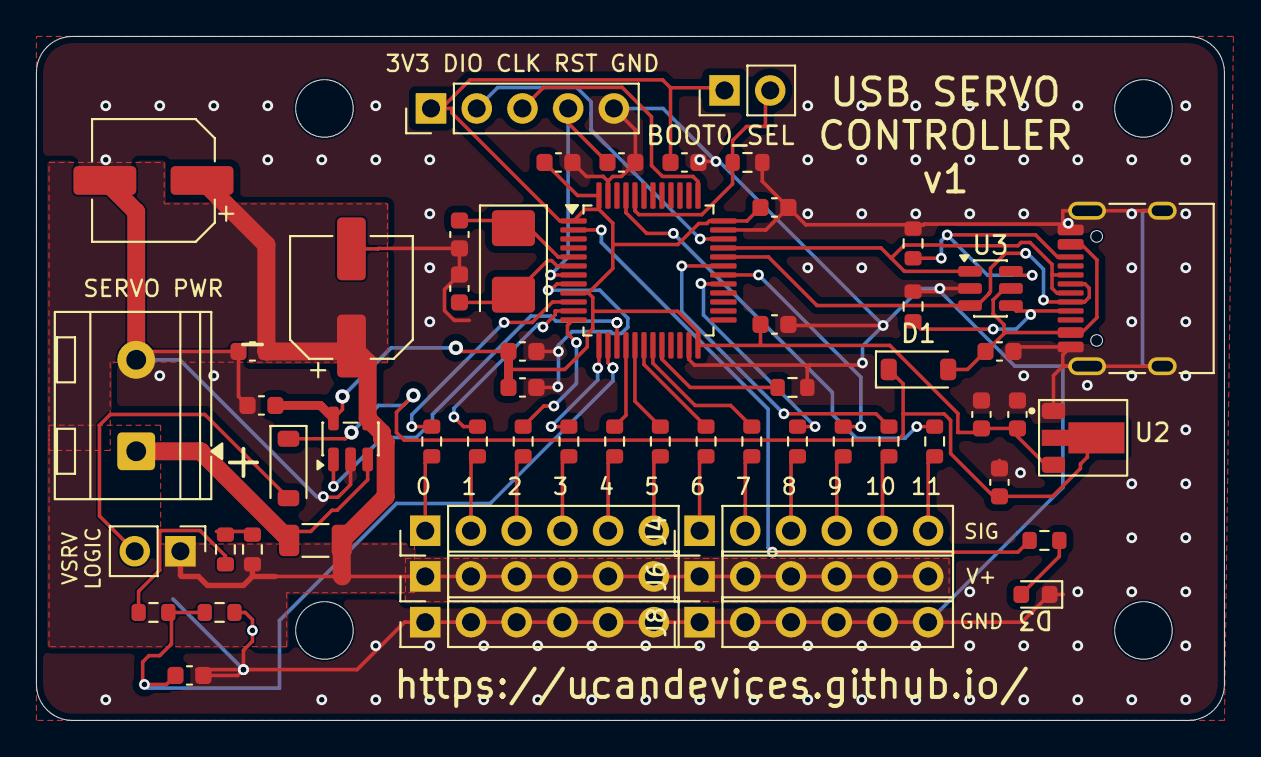
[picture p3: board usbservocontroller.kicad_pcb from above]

Board: 2 copper layers, 66.0 x 38.0 mm, 63 parts (0 on the bottom side), 48 nets.

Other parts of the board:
BOOT0_SEL: BOOT0_SEL; PinHeader_1x02_P2.54mm_Vertical
H1, H2, H3, H4: MountingHole_3.2mm_M3

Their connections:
/+3V3: BOOT0_SEL.1 (A); also elsewhere on the board
/BOOT0: BOOT0_SEL.2 (B); also elsewhere on the board

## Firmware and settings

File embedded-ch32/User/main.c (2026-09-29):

/********************************************************************************
 * main.c -- USB-C 12-Channel Servo Controller, CH32V203C8T6 port.
 *
 * Feasibility port of the STM32F072 firmware in ../embedded. Same board, same
 * schematic, same command protocol; different silicon vendor.
 *
 * Clock: HSE 8 MHz (crystal Y1) x12 = 96 MHz SYSCLK, USB = PLL/2 = 48 MHz.
 ********************************************************************************/

#include "debug.h"
#include "usb_lib.h"
#include "hw_config.h"

#include "servo.h"
#include "sense.h"
#include "protocol.h"
#include "script.h"
#include "maestro.h"
#include "settings.h"

/* Status LED D3: PC13 -> R13 -> anode, cathode to GND, so on = pin high.
   One pattern at a time, highest priority first; t is main-loop ticks (~1 ms).
     fault latched         10 Hz even flashing -- needs a clear (C command)
     script running        steady on
     idle, supply present  one short blip per second
     idle, no servo supply two short blips per second
   The bootloader (bootloader/) blinks an even 5 Hz, distinct from all four. */
static bool led_pattern(uint32_t t)
{
    uint32_t p = t % 1000u;

    if (Sense_Faults() != 0u)
    {
        return ((t / 50u) & 1u) == 0u;
    }
    if (Script_Running())
    {
        return true;
    }
    if (Sense_RailPresent())
    {
        return p < 60u;
    }
    return p < 60u || (p >= 200u && p < 260u);
}

static void led_init(void)
{
    GPIO_InitTypeDef gpio = {0};

    RCC_APB2PeriphClockCmd(RCC_APB2Periph_GPIOC, ENABLE);
    gpio.GPIO_Pin   = GPIO_Pin_13;          /* PC13 -> R13 -> D3 */
    gpio.GPIO_Mode  = GPIO_Mode_Out_PP;
    gpio.GPIO_Speed = GPIO_Speed_2MHz;
    GPIO_Init(GPIOC, &gpio);
}

int main(void)
{
    uint32_t tick = 0;

    NVIC_PriorityGroupConfig(NVIC_PriorityGroup_1);
    SystemCoreClockUpdate();
    Delay_Init();

    led_init();

    /* Bind the servo outputs and start all 12 timers. Every channel comes up
       disabled (idle low) until the host commands a position. */
    Servo_Init();

    /* Stored travel limits and Maestro speed/accel, before anything moves. */
    Settings_Init();

    /* ADC1 plus the two rail-sense pins (PA4 V_SENSE, PA5 I_SENSE). Must come
       after Servo_Init() so nothing is driving a servo pin while the ADC
       calibrates, and before the main loop starts monitoring. */
    Sense_Init();

    /* A stored script marked autorun starts here, with or without a PC. */
    Script_Init();

    /* USB CDC: the command channel. */
    Set_USBConfig();
    USB_Init();
    USB_Interrupts_Config();

    while (1)
    {
        /* Execute any complete command lines buffered by the USB ISR. */
        Protocol_Task();

        /* Watch the servo rail. Trips drop every channel, which de-energises
           the servos and so removes the current -- the board has no series
           protection element, this is what stands in for one. */
        Sense_Task();

        /* Stored script: ramps and instructions, timed off TIM2. */
        Script_Task();

        /* Maestro protocol moves: speed and acceleration ramps, 10 ms steps. */
        Maestro_Task();

        /* A BOOT command hands the chip to the factory USB bootloader. The
           jump happens here, out of interrupt context, after the reply is sent. */
        if (Protocol_BootRequested())
        {
            Protocol_JumpToBootloader();    /* does not return */
        }

        /* Status LED: alive, and what state the board is in -- see led_pattern(). */
        GPIO_WriteBit(GPIOC, GPIO_Pin_13, led_pattern(tick++) ? Bit_SET : Bit_RESET);
        Delay_Ms(1);
    }
}

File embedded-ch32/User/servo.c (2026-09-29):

/********************************************************************************
 * servo.c -- 12-channel servo driver, CH32V203C8T6 port. See servo.h.
 ********************************************************************************/

#include "servo.h"
#include "sense.h"

#define SERVO_PSC   ((SystemCoreClock / SERVO_TIMER_HZ) - 1u)   /* 96M/2M-1 = 47 */
#define SERVO_ARR   (SERVO_FRAME_TICKS - 1u)                    /* 39999        */

typedef struct
{
    TIM_TypeDef  *tim;
    uint8_t       channel;      /* 1..4                                        */
    GPIO_TypeDef *port;
    uint16_t      pin;
    int16_t       adc_channel;  /* ADC_Channel_x, or -1 if not analog-capable  */
} ServoChannel_t;

static const ServoChannel_t s_map[SERVO_CHANNELS] =
{
    /* ch0  */ { TIM2, 1, GPIOA, GPIO_Pin_0,  ADC_Channel_0 },
    /* ch1  */ { TIM2, 2, GPIOA, GPIO_Pin_1,  ADC_Channel_1 },
    /* ch2  */ { TIM2, 3, GPIOA, GPIO_Pin_2,  ADC_Channel_2 },
    /* ch3  */ { TIM2, 4, GPIOA, GPIO_Pin_3,  ADC_Channel_3 },
    /* ch4  */ { TIM3, 1, GPIOA, GPIO_Pin_6,  ADC_Channel_6 },
    /* ch5  */ { TIM3, 2, GPIOA, GPIO_Pin_7,  ADC_Channel_7 },
    /* ch6  */ { TIM3, 3, GPIOB, GPIO_Pin_0,  ADC_Channel_8 },
    /* ch7  */ { TIM3, 4, GPIOB, GPIO_Pin_1,  ADC_Channel_9 },
    /* ch8  */ { TIM1, 1, GPIOA, GPIO_Pin_8,  -1 },
    /* ch9  */ { TIM1, 2, GPIOA, GPIO_Pin_9,  -1 },
    /* ch10 */ { TIM1, 3, GPIOA, GPIO_Pin_10, -1 },
    /* ch11 */ { TIM4, 3, GPIOB, GPIO_Pin_8,  -1 },
};

static uint16_t s_pulse_ticks[SERVO_CHANNELS];
static uint16_t s_min_ticks[SERVO_CHANNELS];
static uint16_t s_max_ticks[SERVO_CHANNELS];
static bool     s_enabled[SERVO_CHANNELS];

static uint32_t s_ms;
static uint32_t s_ms_acc;
static uint16_t s_ms_last_cnt;

/* ------------------------------------------------------------------------- */

static inline uint16_t us_to_ticks(uint16_t us)
{
    return (uint16_t)(us * SERVO_TICKS_PER_US);
}

static inline uint16_t ticks_to_us(uint16_t ticks)
{
    return (uint16_t)(ticks / SERVO_TICKS_PER_US);
}

static void write_ccr(const ServoChannel_t *c, uint16_t ticks)
{
    switch (c->channel)
    {
        case 1: TIM_SetCompare1(c->tim, ticks); break;
        case 2: TIM_SetCompare2(c->tim, ticks); break;
        case 3: TIM_SetCompare3(c->tim, ticks); break;
        default: TIM_SetCompare4(c->tim, ticks); break;
    }
}

static void timer_base_init(TIM_TypeDef *tim)
{
    TIM_TimeBaseInitTypeDef tb = {0};

    tb.TIM_Prescaler         = (uint16_t)SERVO_PSC;
    tb.TIM_CounterMode       = TIM_CounterMode_Up;
    tb.TIM_Period            = (uint16_t)SERVO_ARR;
    tb.TIM_ClockDivision     = TIM_CKD_DIV1;
    tb.TIM_RepetitionCounter = 0;
    TIM_TimeBaseInit(tim, &tb);
    TIM_ARRPreloadConfig(tim, ENABLE);
}

static void timer_channel_init(const ServoChannel_t *c)
{
    TIM_OCInitTypeDef oc = {0};

    oc.TIM_OCMode      = TIM_OCMode_PWM1;
    oc.TIM_OutputState = TIM_OutputState_Enable;
    oc.TIM_Pulse       = 0;                 /* idle low until commanded */
    oc.TIM_OCPolarity  = TIM_OCPolarity_High;

    switch (c->channel)
    {
        case 1: TIM_OC1Init(c->tim, &oc); TIM_OC1PreloadConfig(c->tim, TIM_OCPreload_Enable); break;
        case 2: TIM_OC2Init(c->tim, &oc); TIM_OC2PreloadConfig(c->tim, TIM_OCPreload_Enable); break;
        case 3: TIM_OC3Init(c->tim, &oc); TIM_OC3PreloadConfig(c->tim, TIM_OCPreload_Enable); break;
        default: TIM_OC4Init(c->tim, &oc); TIM_OC4PreloadConfig(c->tim, TIM_OCPreload_Enable); break;
    }
}

void Servo_Init(void)
{
    GPIO_InitTypeDef gpio = {0};
    uint8_t ch;

    RCC_APB2PeriphClockCmd(RCC_APB2Periph_GPIOA | RCC_APB2Periph_GPIOB |
                           RCC_APB2Periph_TIM1  | RCC_APB2Periph_AFIO, ENABLE);
    RCC_APB1PeriphClockCmd(RCC_APB1Periph_TIM2 | RCC_APB1Periph_TIM3 |
                           RCC_APB1Periph_TIM4, ENABLE);

    /* All 12 servo pins: alternate-function push-pull. */
    gpio.GPIO_Mode  = GPIO_Mode_AF_PP;
    gpio.GPIO_Speed = GPIO_Speed_50MHz;
    for (ch = 0; ch < SERVO_CHANNELS; ch++)
    {
        gpio.GPIO_Pin = s_map[ch].pin;
        GPIO_Init(s_map[ch].port, &gpio);
    }

    timer_base_init(TIM1);
    timer_base_init(TIM2);
    timer_base_init(TIM3);
    timer_base_init(TIM4);

    for (ch = 0; ch < SERVO_CHANNELS; ch++)
    {
        s_pulse_ticks[ch] = us_to_ticks(SERVO_US_NEUTRAL);
        s_min_ticks[ch]   = us_to_ticks(SERVO_US_MIN);
        s_max_ticks[ch]   = us_to_ticks(SERVO_US_MAX);
        s_enabled[ch]     = false;
        timer_channel_init(&s_map[ch]);
        write_ccr(&s_map[ch], 0);
    }

    TIM_Cmd(TIM1, ENABLE);
    TIM_Cmd(TIM2, ENABLE);
    TIM_Cmd(TIM3, ENABLE);
    TIM_Cmd(TIM4, ENABLE);

    /* TIM1 is an advanced timer: outputs stay high-Z until MOE is set. */
    TIM_CtrlPWMOutputs(TIM1, ENABLE);
}

bool Servo_SetPulseTicks(uint8_t ch, uint16_t ticks)
{
    if (ch >= SERVO_CHANNELS)
    {
        return false;
    }
    if (ticks < s_min_ticks[ch]) { ticks = s_min_ticks[ch]; }
    if (ticks > s_max_ticks[ch]) { ticks = s_max_ticks[ch]; }

    s_pulse_ticks[ch] = ticks;
    s_enabled[ch]     = true;
    write_ccr(&s_map[ch], ticks);
    return true;
}

bool Servo_SetPulseUs(uint8_t ch, uint16_t us)
{
    return Servo_SetPulseTicks(ch, us_to_ticks(us));
}

uint16_t Servo_GetPulseTicks(uint8_t ch)
{
    if (ch >= SERVO_CHANNELS || !s_enabled[ch])
    {
        return 0u;
    }
    return s_pulse_ticks[ch];
}

uint16_t Servo_GetPulseUs(uint8_t ch)
{
    return ticks_to_us(Servo_GetPulseTicks(ch));
}

uint16_t Servo_LastPulseUs(uint8_t ch)
{
    return (ch < SERVO_CHANNELS) ? ticks_to_us(s_pulse_ticks[ch]) : 0u;
}

bool Servo_SetLimitsUs(uint8_t ch, uint16_t min_us, uint16_t max_us)
{
    if (ch >= SERVO_CHANNELS || min_us < SERVO_US_ABS_MIN || max_us > SERVO_US_ABS_MAX ||
        min_us >= max_us)
    {
        return false;
    }
    s_min_ticks[ch] = us_to_ticks(min_us);
    s_max_ticks[ch] = us_to_ticks(max_us);
    if (s_enabled[ch])
    {
        Servo_SetPulseTicks(ch, s_pulse_ticks[ch]);     /* re-clamp */
    }
    return true;
}

void Servo_GetLimitsUs(uint8_t ch, uint16_t *min_us, uint16_t *max_us)
{
    if (ch >= SERVO_CHANNELS)
    {
        *min_us = *max_us = 0u;
        return;
    }
    *min_us = ticks_to_us(s_min_ticks[ch]);
    *max_us = ticks_to_us(s_max_ticks[ch]);
}

bool Servo_SetEnabled(uint8_t ch, bool enabled)
{
    if (ch >= SERVO_CHANNELS)
    {
        return false;
    }
    s_enabled[ch] = enabled;
    write_ccr(&s_map[ch], enabled ? s_pulse_ticks[ch] : 0u);
    return true;
}

bool Servo_IsEnabled(uint8_t ch)
{
    return (ch < SERVO_CHANNELS) && s_enabled[ch];
}

void Servo_DisableAll(void)
{
    uint8_t ch;
    for (ch = 0; ch < SERVO_CHANNELS; ch++)
    {
        Servo_SetEnabled(ch, false);
    }
}
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

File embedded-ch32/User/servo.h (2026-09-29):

/********************************************************************************
 * servo.h -- 12-channel servo output driver, CH32V203C8T6 port.
 *
 * Channel -> timer mapping follows the same schematic as the STM32 build
 * (PCB/usbservocontroller). The CH32V203 is STM32F103-pin-compatible, so every
 * servo pin keeps its board position; only the timer behind channel 11 differs,
 * because the CH32V203 has TIM4 where the STM32F072 had TIM16:
 *
 *   ch0..ch3   PA0,PA1,PA2,PA3   TIM2_CH1..CH4
 *   ch4..ch7   PA6,PA7,PB0,PB1   TIM3_CH1..CH4
 *   ch8..ch10  PA8,PA9,PA10      TIM1_CH1..CH3
 *   ch11       PB8               TIM4_CH3      (was TIM16_CH1 on STM32F072)
 *
 * Clock tree (see main.c): HSE 8 MHz x12 = 96 MHz SYSCLK.
 *   APB2 /1 -> 96 MHz -> TIM1
 *   APB1 /2 -> 48 MHz, x2 timer rule -> 96 MHz -> TIM2/3/4
 * So all four timers see 96 MHz; PSC=47 gives a 2 MHz tick (0.5 us) and
 * ARR=39999 gives a 20.000 ms frame (50 Hz), identical to the STM32 build.
 ********************************************************************************/

#ifndef __SERVO_H
#define __SERVO_H

#ifdef __cplusplus
extern "C" {
#endif

#include "debug.h"
#include <stdbool.h>
#include <stdint.h>

#define SERVO_CHANNELS      12u

#define SERVO_TIMER_HZ      2000000u
#define SERVO_TICKS_PER_US  (SERVO_TIMER_HZ / 1000000u)   /* = 2 */
#define SERVO_FRAME_TICKS   40000u

/* Default per-channel travel limits -- safe for any hobby servo. */
#define SERVO_US_MIN        500u
#define SERVO_US_MAX        2500u
#define SERVO_US_NEUTRAL    1500u

/* How far the limits can be widened (ESCs, continuous-rotation servos, other
   actuators), the same bounds a Pololu Maestro allows. */
#define SERVO_US_ABS_MIN    64u
#define SERVO_US_ABS_MAX    4080u

void     Servo_Init(void);
/* Every width is clamped to the channel's limits (Servo_SetLimitsUs). */
bool     Servo_SetPulseUs(uint8_t ch, uint16_t us);
/* Same, in timer ticks: 0.5 us each (SERVO_TICKS_PER_US per us). */
bool     Servo_SetPulseTicks(uint8_t ch, uint16_t ticks);
uint16_t Servo_GetPulseUs(uint8_t ch);
/* Output width in ticks, 0 if the channel is off. */
uint16_t Servo_GetPulseTicks(uint8_t ch);
/* Last width commanded, even while the channel is off (1500 if never set):
   where an unpowered servo was most likely left. */
uint16_t Servo_LastPulseUs(uint8_t ch);
bool     Servo_SetEnabled(uint8_t ch, bool enabled);
/* Travel limits, SERVO_US_ABS_MIN <= min < max <= SERVO_US_ABS_MAX. A running
   channel outside the new limits is moved inside them at once. */
bool     Servo_SetLimitsUs(uint8_t ch, uint16_t min_us, uint16_t max_us);
void     Servo_GetLimitsUs(uint8_t ch, uint16_t *min_us, uint16_t *max_us);
bool     Servo_IsEnabled(uint8_t ch);
void     Servo_DisableAll(void);

/* Milliseconds since power-up, counted off TIM2 (the servo timer). Call at
   least once per 20 ms frame -- the main loop does, every ~1 ms. */
uint32_t Servo_Millis(void);

bool     Servo_HasAnalog(uint8_t ch);
bool     Servo_ReadAnalog(uint8_t ch, uint16_t *value);
/* PA4/PA5 are no longer spare analog inputs -- they are the rail voltage and
   current sense pins. See sense.h. */

#ifdef __cplusplus
}
#endif

#endif /* __SERVO_H */

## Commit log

2026-09-29 USB-C 12-channel servo controller: hardware, firmware and host tools
    KiCad 10 schematic and PCB, CH32V203 firmware with USB bootloader,
    rail current/voltage protection and on-board script engine, and
    Python host tools (library, CLI, GUI, script compiler, MCP server).
    [usbservocontroller.kicad_pcb, usbservocontroller.kicad_sch]
2026-09-29 Firmware 0.4: Pololu Maestro serial protocols, per-channel limits, stored settings
    - Maestro Compact / Pololu / Mini SSC protocols alongside the ASCII protocol,
    with on-board speed and acceleration ramps (User/maestro.c)
    - Per-channel travel limits, 64..4080 us (R command), 0.5 us output resolution
    - Settings page in flash (User/settings.c): limits and Maestro start-up
    speed/accel, saved with W, kept across power-off and firmware updates
    - Script save now erases only its own 2 KB, next to the settings page
    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
2026-10-17 README: add demo video and board photo
2026-10-23 Package the MCP server for PyPI and the MCP Registry (ucan-servo-mcp)
2026-10-23 MCP Registry: publish as io.github.Lukasz-Juranek/usb-servo-controller (0.4.1)
    The registry's GitHub login only grants the personal namespace, so the
    entry moves there. Published to PyPI as ucan-servo-mcp 0.4.1 and to the
    MCP Registry.
